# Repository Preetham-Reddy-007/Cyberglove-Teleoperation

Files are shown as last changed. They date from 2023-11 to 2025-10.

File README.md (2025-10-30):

# Cyberglove Teleoperation

A real-time teleoperation system that uses a sensor-equipped cyber glove to remotely control a Dobot robotic arm. The system captures hand movements and finger positions through flex sensors and an IMU, transmitting the data wirelessly via MQTT to control a robotic gripper with precision.

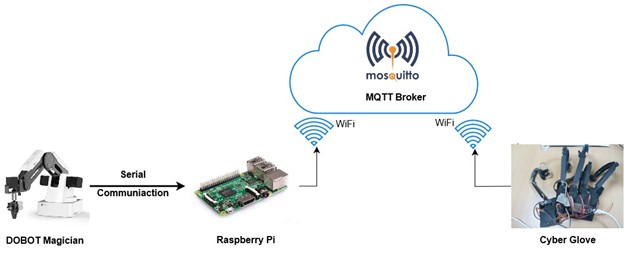
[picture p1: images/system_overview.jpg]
Cyberglove System Overview


## Table of Contents
- [Overview](#overview)
- [Features](#features)
- [System Architecture](#system-architecture)
- [Hardware Components](#hardware-components)
- [Software Components](#software-components)
- [Circuit Diagram](#circuit-diagram)
- [3D Printed Components](#3d-printed-components)
- [Installation](#installation)
- [Usage](#usage)
- [MQTT Communication](#mqtt-communication)
- [Directory Structure](#directory-structure)
- [Dependencies](#dependencies)
- [License](#license)

## Overview

The Cyberglove Teleoperation system enables intuitive remote control of robotic manipulators through natural hand movements. The system consists of:

1. **Cyber Glove**: A wearable device with flex sensors that measure finger joint angles (0-107 degrees) and an MPU6050 IMU for hand orientation tracking
2. **ESP32 Microcontroller**: Processes sensor data and transmits it via MQTT protocol
3. **MQTT Broker**: Handles wireless communication between the glove and robot controller
4. **Robot Controller**: Python-based controller that receives commands and operates the Dobot robotic arm
5. **Feedback System**: Provides force feedback via servos and tactile feedback via vibration motors

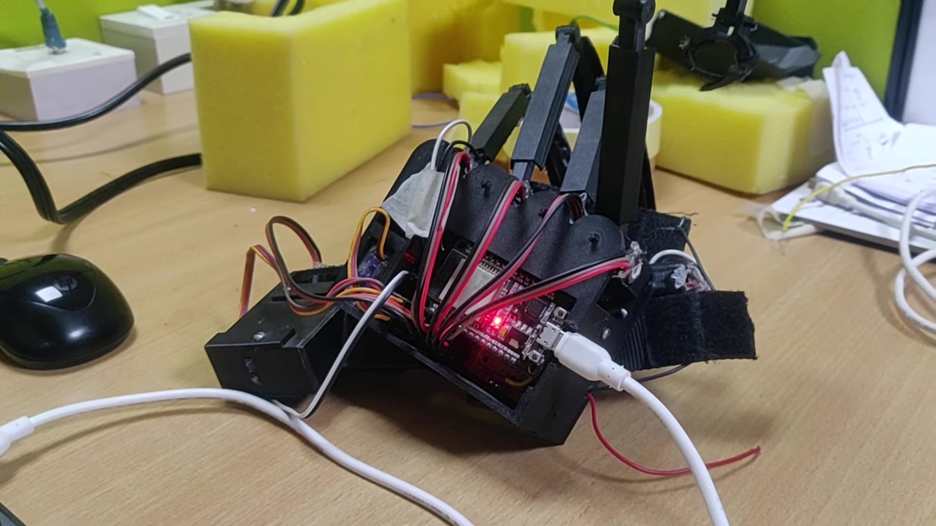
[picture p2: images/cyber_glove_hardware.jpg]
Cyber Glove Hardware


## Features

### Sensing Capabilities
- **5-Finger Joint Angle Tracking**: Independent measurement for thumb, index, middle, ring, and little fingers
- **Hand Orientation Tracking**: Real-time roll, pitch, and yaw angles using MPU6050 IMU
- **Second-Order Butterworth Filter**: Applied to sensor readings for noise reduction
- **20-Sample Moving Average**: Additional smoothing for potentiometer readings

### Control Features
- **Real-Time Teleoperation**: Low-latency control via MQTT protocol
- **Workspace Limitation**: Safety constraints (195-270mm radial workspace, 0-150mm vertical range)
- **Gripper Control**: Open/close gripper based on finger position
- **Web Interface**: Real-time visualization of joint angles and orientation via WebSocket

### Feedback Systems
- **Force Feedback**: Servo motors provide resistance when gripping objects
- **Tactile Feedback**: Vibration motors simulate touch sensations
- **Visual Feedback**: Web-based dashboard showing all sensor values

## System Architecture

The system uses a distributed architecture with the following components:

```
┌─────────────────┐         ┌──────────────┐         ┌─────────────────┐
│   Cyber Glove   │         │     MQTT     │         │  Dobot Robot    │
│   (ESP32)       │◄───────►│    Broker    │◄───────►│  Controller     │
│  - Flex Sensors │  WiFi   │              │  WiFi   │  (Python)       │
│  - IMU (MPU6050)│         │              │         │  - pydobot      │
│  - Servos       │         │              │         │  - paho-mqtt    │
│  - Vibrators    │         │              │         │                 │
└─────────────────┘         └──────────────┘         └─────────────────┘
        │                                                      │
        │                                                      │
        ▼                                                      ▼
┌─────────────────┐                              ┌─────────────────┐
│  Web Interface  │                              │  Robot Actions  │
│  (WebSocket)    │                              │  - Move (X,Y,Z) │
│  - Joint Angles │                              │  - Grip/Release │
│  - Orientation  │                              │  - Workspace    │
└─────────────────┘                              └─────────────────┘
```

## Hardware Components

### Cyber Glove Components

| Component | Model/Type | Quantity | Purpose |
|---|---|---|---|
| Microcontroller | ESP32 | 1 | Main processor for sensor reading and communication |
| IMU | MPU6050 | 1 | Measures hand orientation (roll, pitch, yaw) |
| Flex Sensors | Analog Potentiometers | 5 | Measure finger joint angles |
| Servo Motors | Standard Servo | 2 | Provide force feedback (thumb & index) |
| Vibration Motors | DC Vibration Motors | 2 | Provide tactile feedback |
| 3D Printed Parts | PLA/ABS | Multiple | Mechanical structure and sensor mounting |

### Pin Configuration (ESP32)

**Analog Input Pins (Flex Sensors):**
- GPIO 36: Thumb sensor
- GPIO 39: Index finger sensor
- GPIO 34: Middle finger sensor
- GPIO 35: Ring finger sensor
- GPIO 32: Little finger sensor

**Servo Control Pins:**
- GPIO 25: Thumb servo
- GPIO 33: Index finger servo

**Vibration Motor Pins:**
- GPIO 2: Thumb vibration motor
- GPIO 4: Index finger vibration motor

**IMU Interface:**
- GPIO 21: SDA (I2C Data)
- GPIO 22: SCL (I2C Clock)
- GPIO 5: Interrupt pin

**Status LED:**
- GPIO 17: System status LED

## Software Components

### 1. Cyber Glove Firmware
- **File**: `Cyber Glove/Project_iot_cyber_glove/cyber_glove_release_sw/cyber_glove_release_sw.ino`
- **Functions**:
  - Reads 5 flex sensors with second-order Butterworth filtering
  - Processes MPU6050 IMU data using DMP (Digital Motion Processor)
  - Hosts web server for visualization (port 80)
  - WebSocket server for real-time updates (port 81)
  - Controls force and tactile feedback systems

### 2. ESP32 MQTT Publisher
- **File**: `ESP32/Mosquitto_Write/Mosquitto_Write.ino`
- **Functions**:
  - Reads 4 potentiometer values (X, Y, Z, Gripper)
  - Applies 20-sample moving average filter
  - Maps sensor values to 0-127 range
  - Publishes data to MQTT topic `ESP32/Potentiometerdataread` every 5 seconds

### 3. Dobot Robot Controller
- **File**: `Dobot/PahoFinal.py`
- **Functions**:
  - Subscribes to MQTT topic for glove data
  - Maps sensor values to robot workspace coordinates
  - Enforces workspace constraints (195-270mm radial, 0-150mm height)
  - Controls Dobot arm position and gripper state
  - Uses pydobot library for robot communication

### 4. Additional Scripts
- `Dobot/FinalWspc.py`: Alternative workspace configuration
- `Dobot/PahoFinal2.py`: Alternative MQTT implementation
- `PahoConnect.py`: MQTT connection testing utility

### Sensor Calibration Values

The system uses calibration offsets for accurate angle measurement:

```cpp
// Joint Angle Offsets (raw ADC values)
const float ind_off = 878.0;   // Index finger
const float mid_off = 785.0;   // Middle finger
const float rng_off = 1179.0;  // Ring finger
const float lil_off = 950.0;   // Little finger
const float thb_off = 895.0;   // Thumb

// Joint Angle Ranges (raw ADC values)
const float ind_range = 1794.0;
const float mid_range = 1708.0;
const float rng_range = 1684.0;
const float lil_range = 1845.0;
const float thb_range = 1958.0;

// Angular range in degrees
const float delta_ang = 107.0;
```

## 3D Printed Components

The cyber glove uses custom 3D printed parts for mechanical structure and sensor mounting. STL files are provided for both right-hand (default) and left-hand configurations.

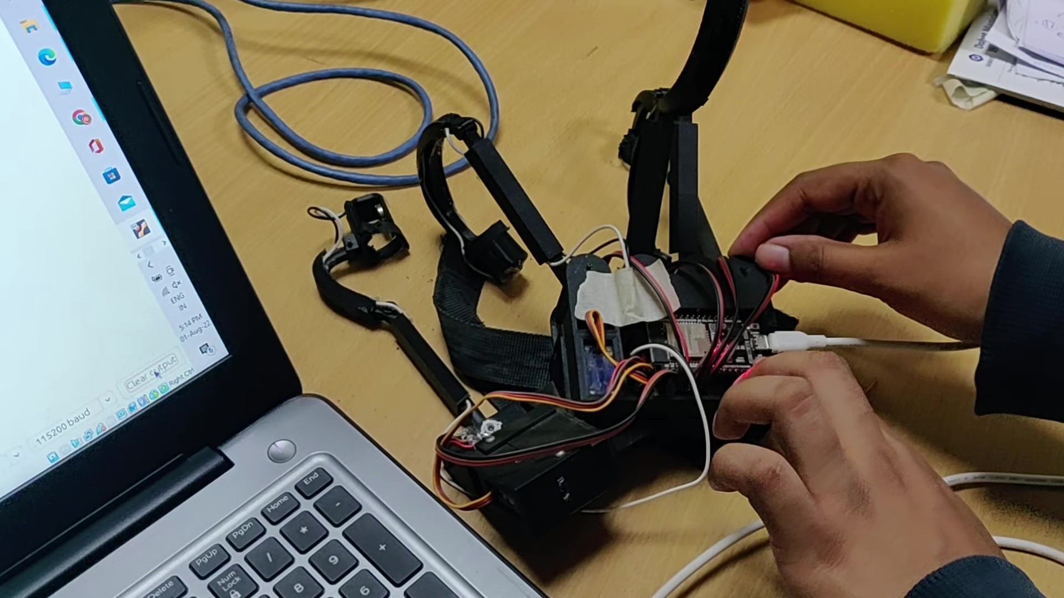
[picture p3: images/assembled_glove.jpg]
Assembled Glove


### Parts List

**Finger Mechanisms:**
- `bottom holder.STL` / `top holder.STL`: Main mounting brackets
- `mid_ring_ind_finger link.STL`: Link mechanism for index, middle, ring fingers
- `mid_ring_ind_finger cover.STL`: Protective cover
- `little finger link.STL` / `little finger cover.STL`: Little finger mechanism
- `thumb attachment.STL` / `thumblink.STL`: Thumb mechanism
- `thumb upper holder.STL` / `thumb lower holder.STL`: Thumb mounting
- `thumb cover.STL` / `thbl2cvr.STL`: Thumb protective covers

**Sensor Mounts:**
- `finger tip version1.STL`: Fingertip sensor housing
- `tip with mot.STL`: Motorized fingertip
- `rachet_joint.STL`: Ratcheting joint mechanism
- `rachet link.STL` / `rachet link cover.STL`: Ratchet link assembly

**Electronics Housing:**
- `pcbholder.STL`: PCB mounting bracket
- `cover plate.STL`: Electronics cover
- `slider2.STL` / `slide1_1_1.STL` / `slide_1_1_2.STL`: Adjustment sliders

**Left-Hand Version:**
All parts are available in mirrored versions in the `STL_Files_Left_Hand/` directory.

### Printing Recommendations

- **Material**: PLA or ABS
- **Layer Height**: 0.2mm
- **Infill**: 20-30%
- **Supports**: Required for some parts
- **Print Orientation**: Follow guidelines in `STL_Files_Left_Hand/Readme cyber glove prints.pdf`

## Installation

### Hardware Setup

1. **3D Print Components**
   - Print all required STL files from the `Cyber Glove/cyber glove/` directory
   - Use appropriate material (PLA/ABS) with 20-30% infill
   - Refer to `STL_Files_Left_Hand/Readme cyber glove prints.pdf` for printing guidelines

2. **Assemble Cyber Glove**
   - Mount flex sensors in finger mechanisms
   - Install MPU6050 IMU on the back of hand
   - Connect servos for force feedback
   - Install vibration motors
   - Wire all components to ESP32 according to pin configuration

3. **Connect Dobot Robot**
   - Connect Dobot arm to computer via USB (typically `/dev/ttyUSB2` on Linux)
   - Ensure robot is powered and initialized

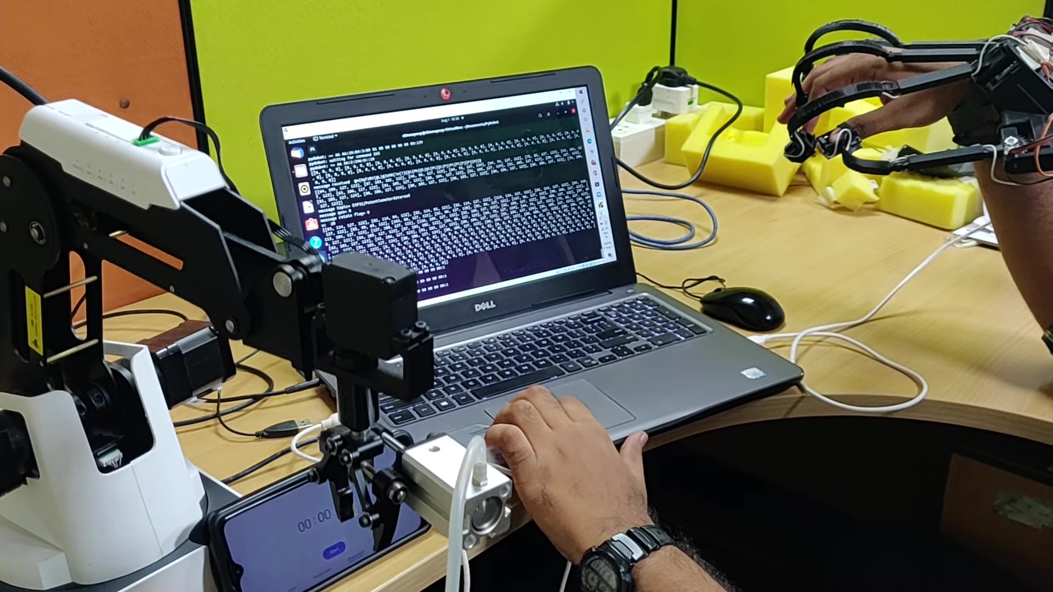
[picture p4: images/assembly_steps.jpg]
Assembly Steps


### Software Setup

#### 1. ESP32 Firmware

Install required libraries in Arduino IDE:
```bash
# Arduino Libraries needed:
- WiFi (built-in)
- PubSubClient
- ArduinoJson
- WebSocketsServer
- ESP32Servo
- MPU6050 (I2Cdev library)
```

Configure WiFi and MQTT:
```cpp
// In cyber_glove_release_sw.ino or Mosquitto_Write.ino
const char* ssid = "YOUR_WIFI_SSID";
const char* password = "YOUR_WIFI_PASSWORD";
const char* mqtt_server = "YOUR_MQTT_BROKER_IP";
```

Upload firmware to ESP32.

#### 2. MQTT Broker

Install Mosquitto MQTT broker:
```bash
# Ubuntu/Debian
sudo apt-get update
sudo apt-get install mosquitto mosquitto-clients

# macOS
brew install mosquitto

# Start the broker
mosquitto -v
```

Or use a cloud MQTT broker:
- `broker.mqtt-dashboard.com`
- `broker.emqx.io`

#### 3. Python Environment

Install Python dependencies:
```bash
pip install pydobot paho-mqtt
```

For Dobot robot, you may need additional setup:
```bash
# Linux: Add user to dialout group for USB access
sudo usermod -a -G dialout $USER
```

Configure Python script:
```python
# In Dobot/PahoFinal.py
broker_address = "YOUR_MQTT_BROKER_IP"  # e.g., "192.168.1.100"
port = "/dev/ttyUSB2"  # Adjust for your system (COM port on Windows)
```

## Usage

### 1. Start MQTT Broker

```bash
mosquitto -v
```

### 2. Power On Cyber Glove

- Power the ESP32 (via USB or battery)
- Wait for WiFi connection (check Serial Monitor)
- Note the IP address displayed

### 3. Access Web Interface

Open a browser and navigate to the ESP32's IP address:
```
http://[ESP32_IP_ADDRESS]
```

The interface displays:
- Real-time finger joint angles
- Hand orientation (roll, pitch, yaw)
- Force feedback status
- Tactile feedback status
- Control buttons for feedback activation

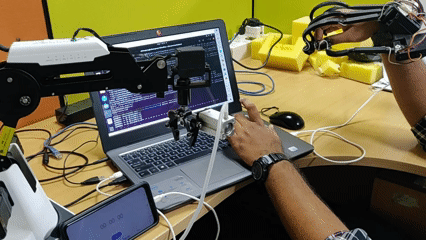
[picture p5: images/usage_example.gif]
Usage Example


### 4. Start Robot Controller

```bash
cd Dobot
python PahoFinal.py
```

The script will:
- Connect to MQTT broker
- Move Dobot to home position (234, 0, 75, 0)
- Subscribe to glove data
- Begin real-time teleoperation

### 5. Operate the System

- Move your hand to control robot position
- Finger movements map to X, Y, Z coordinates
- Close fingers to activate gripper
- System enforces workspace constraints for safety

### Control Mapping

| Glove Input | Robot Output | Range |
|---|---|---|
| X-axis finger angle | Robot X position | 195-270mm |
| Y-axis finger angle | Robot Y position | 195-270mm |
| Z-axis finger angle | Robot Z position | 0-150mm |
| Gripper sensor | Gripper state | Open/Close |
| Hand roll/pitch/yaw | (Future: Wrist orientation) | ±180° |

## MQTT Communication

### Topic Structure

- **Publisher**: ESP32 Cyber Glove
- **Topic**: `ESP32/Potentiometerdataread`
- **Subscriber**: Python Robot Controller
- **Message Format**: 4-byte character array `[X, Y, Z, Gripper]`
- **Update Rate**: Every 5 seconds
- **QoS Level**: 0 (At most once)

### Data Format

```
Message: [dx, dy, dz, dg]
  dx: X-axis value (0-127)
  dy: Y-axis value (0-127)
  dz: Z-axis value (0-127)
  dg: Gripper value (0-127)
    - dg ≤ 63: Grip closed
    - dg > 63: Grip open
```

### Coordinate Transformation

```python
# Sensor to robot workspace mapping
xa = (dx * 270) / 127  # Map to 0-270mm
ya = (dy * 270) / 127
za = (dz * 150) / 127  # Map to 0-150mm

# Workspace validation
radius = sqrt(xa² + ya²)
if 195 <= radius <= 270 and 0 <= za <= 150:
    # Valid workspace - execute movement
    device.move_to(xa, ya, za, r, wait=True)
```

## Directory Structure

```
Cyberglove-Teleoperation/
├── Cyber Glove/
│   ├── Project_iot_cyber_glove/
│   │   ├── cyber_glove_release_sw/          # Main cyber glove firmware
│   │   ├── robot_gripper_release_sw/        # Gripper control firmware
│   │   ├── Readme.pdf                       # Hardware documentation
│   │   ├── presentation_HW_SW_architecture.pdf
│   │   └── system_schematic.pdf             # System wiring diagram
│   └── cyber glove/                         # 3D model STL files (right hand)
│       ├── bottom holder.STL
│       ├── top holder.STL
│       └── [... other STL files]
├── STL_Files_Left_Hand/                     # 3D model STL files (left hand)
│   ├── Readme cyber glove prints.pdf        # Printing instructions
│   └── [... mirrored STL files]
├── Dobot/
│   ├── PahoFinal.py                         # Main robot controller
│   ├── PahoFinal2.py                        # Alternative implementation
│   ├── FinalWspc.py                         # Workspace utilities
│   └── FinalWspc2.py
├── ESP32/
│   ├── Mosquitto_Write/                     # MQTT publisher (simple version)
│   ├── Mosquitto_Write2/
│   ├── Mosquitto_Read/                      # MQTT subscriber test
│   ├── CloudWriteAvg/                       # Cloud MQTT implementation
│   ├── CloudReadAvg/
│   ├── Serial/                              # Serial communication test
│   └── Test_Array/                          # Array data handling test
├── PahoConnect.py                           # MQTT connection tester
├── Documentation.docx                       # Project documentation
├── LICENSE                                  # MIT License
└── README.md                                # This file
```

## Dependencies

### Hardware
- ESP32 Development Board (WROOM-32 or similar)
- MPU6050 6-axis IMU
- 5x Analog flex/potentiometer sensors
- 2x Servo motors (for force feedback)
- 2x Vibration motors (DC motors)
- Dobot Magician robotic arm
- WiFi network
- 3D printer for mechanical parts

### Software

**Arduino Libraries:**
```
WiFi
PubSubClient (MQTT)
ArduinoJson
WebSocketsServer
ESP32Servo
Wire (I2C)
I2Cdev
MPU6050 (DMP)
```

**Python Packages:**
```
pydobot>=1.3.0
paho-mqtt>=1.5.0
```

**System Requirements:**
```
Arduino IDE 1.8.x or higher (or PlatformIO)
Python 3.6 or higher
Mosquitto MQTT Broker 1.6 or higher
```

## Calibration

### Flex Sensor Calibration

1. Open `cyber_glove_release_sw.ino`
2. Read raw ADC values with fingers straight (offsets)
3. Read raw ADC values with fingers fully bent (ranges)
4. Update calibration constants:
   ```cpp
   const float ind_off = YOUR_VALUE;
   const float ind_range = YOUR_VALUE;
   // Repeat for all fingers
   ```

### IMU Calibration

Run the MPU6050 calibration sketch and update:
```cpp
mpu.setXGyroOffset(YOUR_VALUE);
mpu.setYGyroOffset(YOUR_VALUE);
mpu.setZGyroOffset(YOUR_VALUE);
mpu.setZAccelOffset(YOUR_VALUE);
```

### Workspace Calibration

Adjust robot workspace limits in `PahoFinal.py`:
```python
# Radial workspace (mm)
if 195 <= sqrt <= 270:
    # Adjust these values based on your robot

# Vertical workspace (mm)
if 0 <= za <= 150:
    # Adjust these values based on your robot
```

## Troubleshooting

**ESP32 not connecting to WiFi:**
- Verify SSID and password
- Check 2.4GHz WiFi network (ESP32 doesn't support 5GHz)
- Monitor serial output for connection status

**MQTT messages not received:**
- Verify broker is running: `mosquitto -v`
- Check broker IP address in both ESP32 and Python code
- Test with mosquitto_sub: `mosquitto_sub -t "ESP32/Potentiometerdataread"`

**Dobot not responding:**
- Check USB connection and permissions
- Verify port in Python script (e.g., `/dev/ttyUSB2`, `COM3`)
- Ensure pydobot is installed correctly

**Inaccurate sensor readings:**
- Recalibrate flex sensors
- Check for loose connections
- Verify power supply stability
- Adjust filter parameters if needed

## Future Enhancements

- [ ] Add hand orientation control for robot wrist
- [ ] Implement bilateral force feedback
- [ ] Add multiple robot support
- [ ] Develop smartphone app for monitoring
- [ ] Add gesture recognition for complex commands
- [ ] Implement machine learning for motion prediction
- [ ] Add VR/AR visualization
- [ ] Support for other robot platforms

## Contributing

Contributions are welcome! Please feel free to submit pull requests or open issues for bugs and feature requests.

## License

This project is licensed under the MIT License - see the [LICENSE](LICENSE) file for details.

## Acknowledgments

- MPU6050 DMP library by Jeff Rowberg
- pydobot library for Dobot control
- Eclipse Paho for MQTT implementation

## Contact

For questions or support, please open an issue in the GitHub repository.

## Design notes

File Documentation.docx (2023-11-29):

Teleoperation of DOBOT Magician using Cyber Glove

2022

Index

1. Step 1 : Set up the ORACLE Virtual Box
2. Step 2 : Arduino IDE Installation and ESP 32 Package Installation
3. Step 3 : DOBOT Magician Python API Interface and Setup
4. Step 4 : MQTT Protocol Implementation

ORACLE Virtual Box

Note: If you work on an Ubuntu System, you can skip this step.

Installing Oracle Virtual Box (VB) : Oracle Website -> Windows host -> download latest version

When you want to update Virtual Box to latest version, uninstall and download the latest file from their website. The virtual machines will be auto present when you open the updated virtual box. Don’t upgrade directly, as you might get kernel issues.

Ubuntu ISO : Go to Ubuntu website and download the iso file.

I Setup new Virtual Machine in Oracle VB

All downloads done within virtual box in ubuntu 20.04 .

Open the VB

1. New virtual Machine: Type: Linux

Version: Ubuntu 64bit

Hard Disk: 4000MB

Memory: 25GB

2. System Settings : Install Ubuntu Image (Downloaded earlier) from downloads
3. USB Settings :
- In settings click the USB tab.
- On the right side, click the usb icon with a green plus sign.
- Add anything with Silicon Labs USB to Uart Bridge controllers, or anything with Cygnal
- Integrated products CP210x Uart bridge. If you don't see these Options you many need
- to download drivers for your platform here (https://www.silabs.com/developers/usb-to-uart-bridge-vcp-drivers).

( https://www.silabs.com/developers/usb-to-uart-bridge-vcp-drivers )

- Select English, install Ubuntu
- Select keyboard, English(US)
- Select Normal Installation & Download updates while installing Ubuntu
- Since you are using a virtual machine you can select erase disk and install.
- Username : “Set your username”
- Pswrd : “Set your password”

//Takes time to install.

- Connect your online accounts : Skip
- Right ctrl (Host button) + F : Full screen
- But you might get black screen around the box
- So go to devices -> Insert guest additions CD image -> put your password : it will download -> then shutdown ubuntu -> and start again -> press right ctrl + F

For all Ubuntu distributions run these commands after a fresh install.

- sudo apt install gcc g++ cmake putty unzip curl
- sudo apt update
- sudo apt upgrade
- If you are on a virtual machine (Virtual Box), at the top of the window click Devices
  - Shared Clipboard set to bidirectional
  - Drag and Drop set to bidirectional
  - Finally click Insert guest additions CD Image
  - Once done installing in terminal input reboot

These steps are not mandatory. They just make working inside the virtual box easier.

Arduino IDE Installation and ESP 32 Package Installation

Use snap to download Arduino as given in the following website: https://linoxide.com/how-to-install-arduino-ide-on-ubuntu-20-04/

You need to type ./install.sh instead. The ./ indicates that you want to run a file in your current working directiry. Without the leading ./ linux will search in your $PATH for an executable program with that name.

Follow the following steps to add esp32 dev board package to the ide.

1. Go to File -> Preferences -> In additional boards manager URL : https://dl.espressif.com/dl/package_esp32_index.json
2. Then click Ok
3. Tools -> Boards -> No ES32 -> so go to Boards Manager -> type esp32 -> Install the package that shows up
4. Go to Tools -> Boards -> ESP 32 dev board

(https://randomnerdtutorials.com/installing-the-esp32-board-in-arduino-ide-mac-and-linux-instructions/)

(http://arduino-er.blogspot.com/2020/06/install-esp32esp8266-to-arduino-ide-on.html)

Go through the above two URLs for further reference.

# When IDE is first installed, no libraries are present. So install them from library manager and git hub profiles online as zip files and then add them.

DOBOT Magician Python API Interface and Setup

The DOBOT Magician has a DOBOT API interfaced with a python API. This API can be accessed using the PyDobot library available at : https://github.com/luismesas/pydobot

The setup for the same is as follows,

Terminal:

- Install: Python3 (You will need Python 2.7 or Python 3.x. Download “ https://www.python.org/ “ and install.)
- Pip is a python library manager. Pip drivers and Pip module allow Python functions to run in terminal. ( https://linuxize.com/post/how-to-install-pip-on-ubuntu-18.04/ )
- Install Pydobot (Install Pydobot using pip (command : pip install pydobot))

You can also download its zip file from: https://github.com/luismesas/pydobot

- You will also need pyserial module. pip install pyserial (If pyserial is not installed exceptions will be thrown when executing examples)
- Download the CP210x USB to UART Bridge VCP Drivers from https://www.silabs.com/developers/usb-to-uart-bridge-vcp-drivers
- Use the commands ‘groups’ to check what groups are you a part of. Use ‘sudo usermod -a ubuntu -G dialout’ or ‘newgrp dialout’ to add yourself (username here: ubuntu) to dialout group and similarly to ttl group as well.
- The dialout group helps you control the usb ports without which you will be thrown the error ‘port access denied’.
- And every time you add yourself to a new group make sure you reboot.

To Run the python scripts for Dobot control:

- Open Ubuntu VB
- Open Terminal
- Check if pydobot library is installed : pip3 show pydobot
- Connect DOBOT Magician to laptop using USB port and power it on. The Dobot takes a few seconds to initialize.
- Check Devices -> USB -> Silicon Labs is detected
- Use dmesg command and lusb commands to identify what port is selected and make the corresponding changes in the script (ttyUSB0/1/2 *)

( USB tab under devices may not show the silicon labs port if it isn’t added in the virtual box , so make sure to add it in USB settings in the VB first using the green plus usb icon.)

Note: If the module you are trying to import i.e. the library , and any of your python files are named the same , then you will get a circular error. So make sure they are named differently.

Generally, the Python Circular Import problem occurs when you accidentally name your working file the same as the module name and those modules depend on each other. This way the python opens the same file again and again which causes a circular loop and eventually throws an error.

- In Terminal : execute the file

cd Documents/PyDobot (location where the file is stored)

python3 Py.py (here Py.py is the file you are trying to run)

Note: To compile python files : python -m py_serial Py.py or python3 -m py_serial Py.py

Note: Information on how to operate and troubleshoot technical issues with the Dobot Magician are provided in the manual – Dobot Magician User Guide, download-able from their website.

The Dobot Studio is their official application which can be downloaded from their website and installed on your system.

PyDobot is an unofficial python library that utilizes the python API interfaced with the Dobot API for control of DOBOT Magician.

Note: Fix port access on Linux : https://support.arduino.cc/hc/en-us/articles/360016495679-avrdude-ser-open-can-t-open-device-Permission-denied-Linux-

It will give you the importance of ‘dialout’ group.

Note : When you add yourself to a new group, for the effect to take place the system needs to be rebooted.

The USB connection is not handled by the ESP32, as an ESP32 only has serial lines (rx and tx), no USB. A dev board typically includes some sort of USB to serial converter chip (sometimes refered to as FTDI). This chip communicates with your computer, resulting in the creation of a virtual COM port. If you have a driver for that chip installed, otherwise it won't work. Without a driver the chip probably turns up as unsupported or unrecognized device in your hardware list. Although the ESP32 module may be the same, you might have a dev board with a different USB to serial converter than other devices you might have tested on your computer. So if one dev board works and another one doesn't, that does not necessarily mean the board is defective. You might just need to install a driver for the USB to serial chip on your dev board.

MQTT Protocol Implementation

Refer: Mosquitto MQTT Broker: Tutorial for Installation on Ubuntu 20.04 | ArubaCloud.com (https://www.arubacloud.com/tutorial/how-to-install-and-secure-mosquitto-on-ubuntu-20-04.aspx)

http://mosquitto.org/

Programs included : There are two folders : Dobot and ESP32

Dobot contains the programs used for operating the Dobot Magician.

ESP32 contains the programs running on both the esp32 s.

THINGSPEAK | CloudWriteAvg | Glove | Writes the potentiometer data to ThingSpeak Cloud Server using write API key over HTTP protocol.
| CloudReadAvg | ESP32 | Reads the potentiometer data from ThingSpeak Cloud Server using read API key over HTTP protocol.
| FinalWspc.py | Terminal | Operates the DOBOTMagician in the positive workspace.
MOSQUITTO (No Fidelity) | Mosquitto_Write | Glove | Publishes potentiometer data to the MOSQUITTO Broker running on the computer using MQTT v3.1.1 .
| Mosquitto_Read | ESP32 | Subscribes the potentiometer date from the MOSQUITTO Broker running on the computer using MQTT v3.1.1 .
| FinalWspc.py | Terminal | Operating the DOBOTMagician in the positive workspace.
MOSQUITTO (With Fidelity) | MosquittoWrite2 | Glove | Publishes potentiometer data to the MOSQUITTO Broker running on the computer using MQTT v3.1.1 .
| PahoFinal.py | Terminal | Subscribes to the Mosquitto broker using Paho client.
| Test_Array | Glove | Publishes potentiometer data. Takes 20 values, each at an interval of 250ms. Publishes it at an interval of 7s.
| PahoFinal2.py | Terminal | Subscribes and executes the 20 values.
| PahoFinal2copy.py | Terminal | Subscribes and executes the values but has a buffer to continuously take values from the glove.
Serial | Serial | Glove | Sends Potentiometer Data over serial communication
| FinalWspc.py | Terminal | Operates the DOBOTMagician in the positive workspace.

Extra Programs:

PyDobot2.py : Vanilla program used to operate pydobot. Simple demonstration of the PyDobot library.

Position.py: Prints the cartesian co-ordinates of the end-effector and angular joint positions

Note : When flashing the esp32, press the Boot button continuously until the flashing is executed. Then press the

The EN button is connected to the EN pin on the ESP32, so pressing it will reset the ESP32.

The BOOT button is connected to GPIO0 (which is also a bootstrapping pin to set the boot mode (https://github.com/espressif/esptool/wiki/ESP32-Boot-Mode-Selection)), so pressing it will pull GPIO0 low

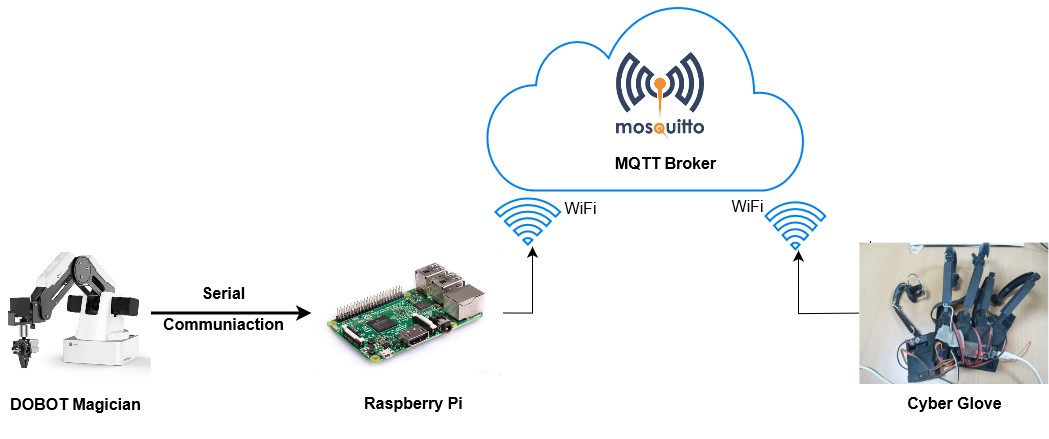
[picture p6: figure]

Protocol : MQTT

Broker : Mosquitto

Publishing Client : Raspberry Pi

Subscribing Client: Cyber Glove

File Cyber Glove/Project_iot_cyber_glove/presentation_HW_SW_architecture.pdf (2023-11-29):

# Cyber Glove

## 1. Objectives revisited 2. System configuration 3. Human Hand anatomy 4. Mechanical design 5. Hardware architecture 6. Software architecture

## System architecture and implementation plan - Preetham Reddy G

# Objectives Revisited

Accurate enough estimation
of kinematics.

Integration of haptic
feedback in the glove

Communication between
Glove and robotic hand

Ergonomic design of glove

Proposed Solution :
- Design of exoskeleton
without affecting any DOF
of hand

Proposed Solution :
- Use of Exoskeleton with
Ratchet mechanism to
provide digital force
feedback.
- Use of vibration motors for tactile feedback (touch)

Proposed Solution :
- WIFI connectivity for Line of sight connectivity
- Use of internet for Long distance communication
through wifi

Proposed Solution :
- Use of Exoskeleton with
rotational encoders for
finger kinematics
- And IMU for Yaw ,Pitch and Roll motion capturing

# Human Hand anatomy

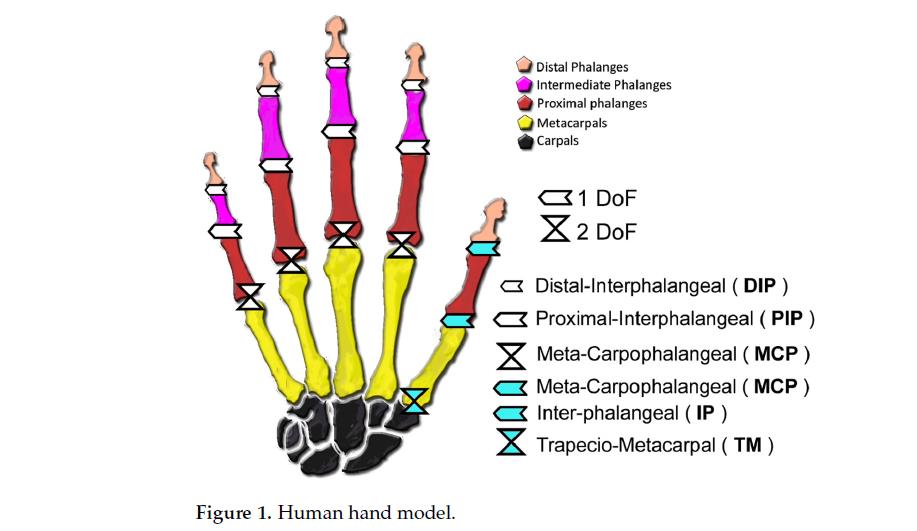
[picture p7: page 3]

# System Configuration

## - Easy to apply rigid body dynamics and kinematics to estimate the finger

kinematics.

## - Rotary encoders can be used which are very cheap (potentiometer)

- Excellent for “Force feedback”.

## exoskeleton helps in restricting the motion of fingers in controlled manner

## Exoskeleton configuration : Mechanical system designed around dynamic

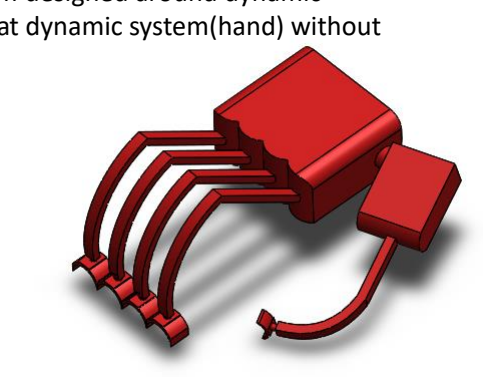
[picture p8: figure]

## system(hand) which mimics the motion of that dynamic system(hand) without

restricting the DOFs.

# Mechanical Design

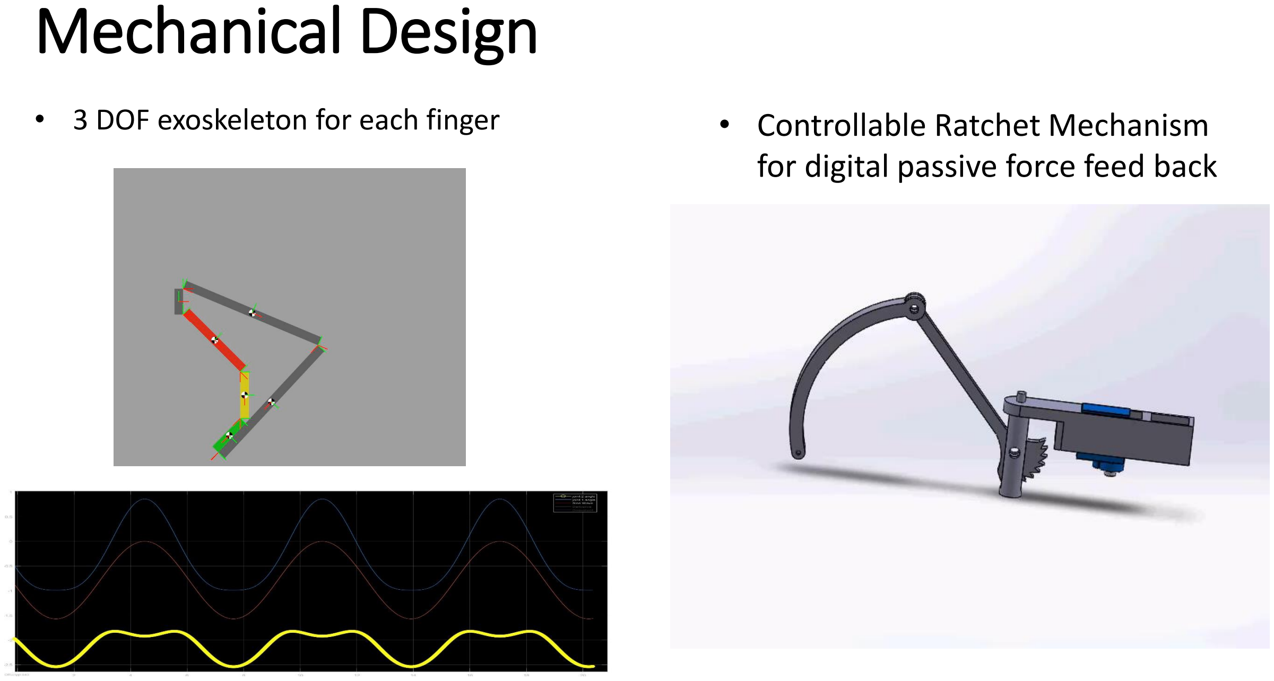
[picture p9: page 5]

- 3 DOF exoskeleton for each finger | • Controllable Ratchet Mechanism for digital passive force feed back

# Hardware architecture

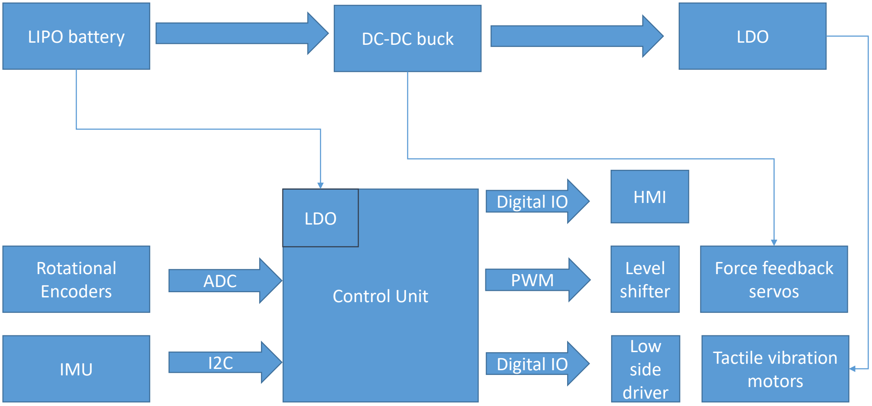
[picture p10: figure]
Rotational; Encoders; Control Unit; IMU; Force feedback servos; Tactile vibration motors; Low side driver; Level shifter ADC; PWM; Digital IO; LIPO battery; DC-DC buck; LDO; HMI

# Software Architecture

SOC abstraction layer

System On Chip

ADC drivers | PWM drivers | Digital IO | I2c comm.
drivers | Wi-Fi drivers

System related drivers

Hardware abstraction layer
Servo drive | Tactile Motor
drive | Encoder sensor | IMU | Power supply monitoring

Application layer

Kinematics
algorithm

IMU filter
algorithm

Haptic feedback
algorithm | HMI | Communication

# Small demo of active feedback

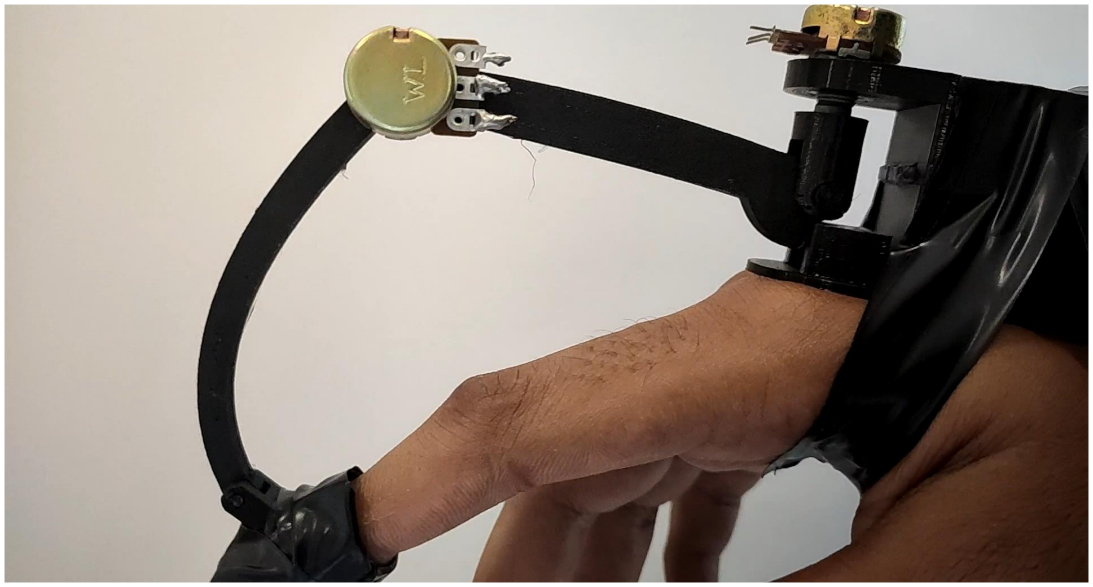
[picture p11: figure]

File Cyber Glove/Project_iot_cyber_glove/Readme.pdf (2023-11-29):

## The attached files are:

1. presentation_HW_SW_architecture.pptx
2. system_schematic.pdf
3. cyber_glove_release_sw.ino
4. robot_gripper_release_sw.ino
5. glove_server.txt

presentation_HW_SW_architecture.pptx :
This ppt has all the details regarding high level system design

### system_schematic.pdf :

This document has schematic level design which also includes boundary condition analysis, power calculation.

### cyber_glove_release_sw.ino :

This is final release of software version for exoskeleton based cyber glove which include sw components for

1. HW description
2. Calibration parameters
3. IMU
4. Rotary sensor interfacing with filtering.
5. Force feedback
6. Touch feedback
7. Websocket server
8. Webpage for testing

### robot_gripper_release_sw.ino :

This is final release of software version for Robot gripper and includes SW components for

1. HW description
2. Calibration parameters
3. Servo control
4. Pressure sensor interface and filtering
5. Websocket client

### glove_server.txt:

This has html description of webpage and java script for the same.

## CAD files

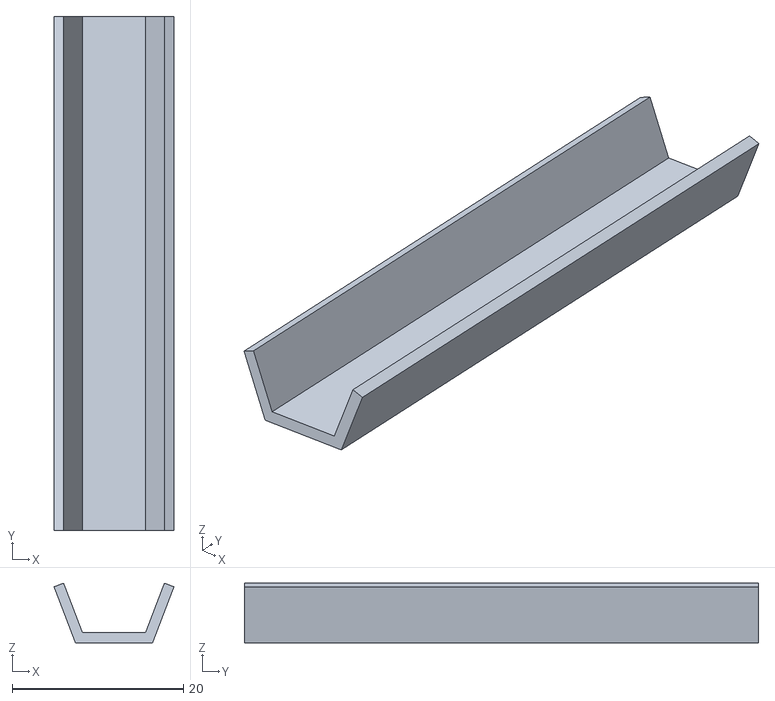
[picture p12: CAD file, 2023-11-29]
Cyber Glove/cyber glove/rachet link cover.STL
14.0 x 60.0 x 6.97

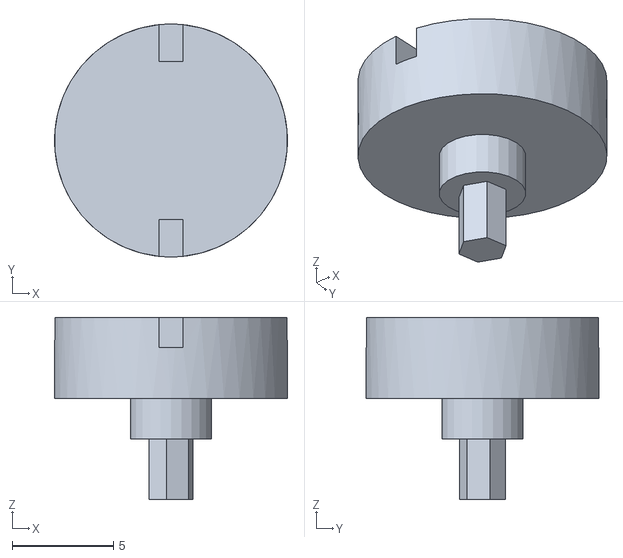
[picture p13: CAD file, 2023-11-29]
STL_Files_Left_Hand/Ratchet Joint 3.stl
11.5 x 11.5 x 9.00

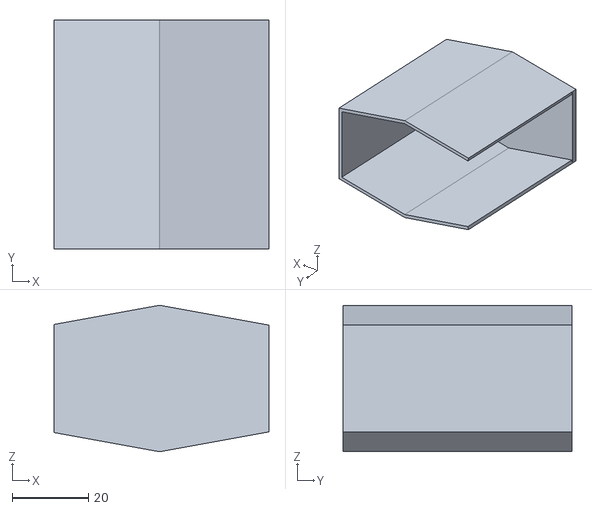
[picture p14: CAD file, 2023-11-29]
Cyber Glove/cyber glove/thumb cover.STL
56.4 x 60.0 x 38.4

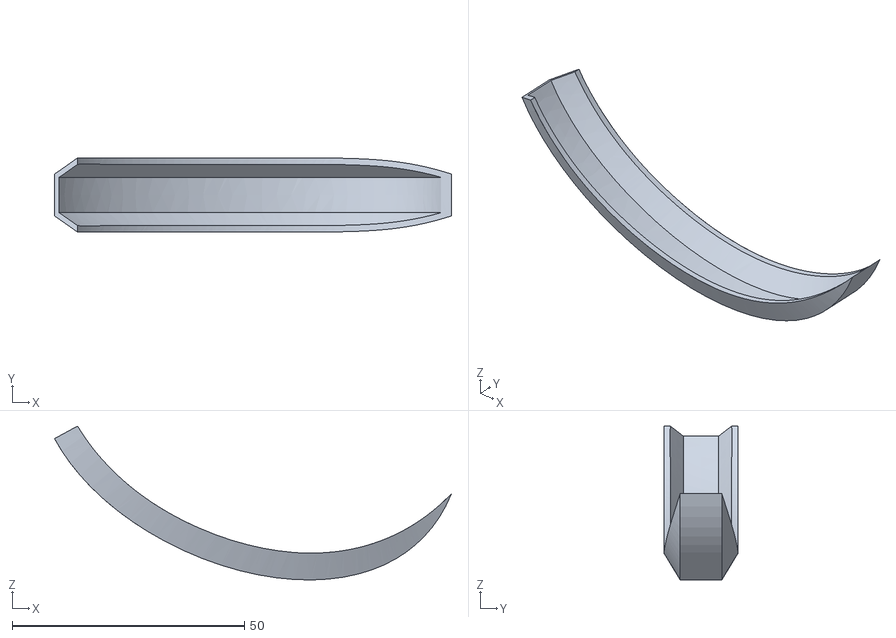
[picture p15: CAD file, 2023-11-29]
Cyber Glove/cyber glove/mid_ring_ind_finger cover.STL
85.5 x 16.0 x 33.1

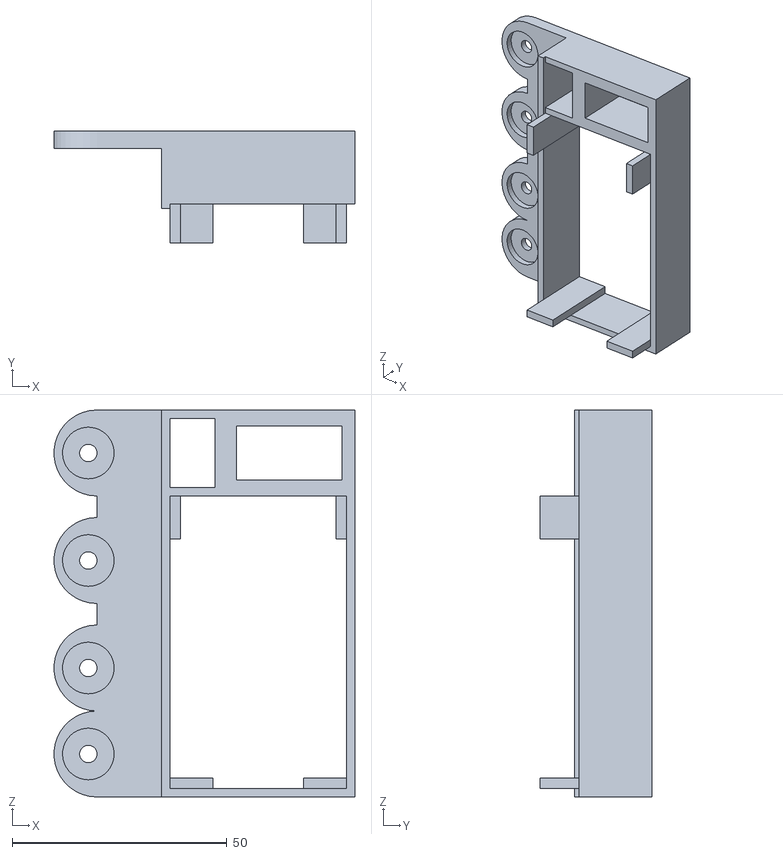
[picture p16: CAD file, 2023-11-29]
Cyber Glove/cyber glove/top holder.STL
70.0 x 26.0 x 90.0

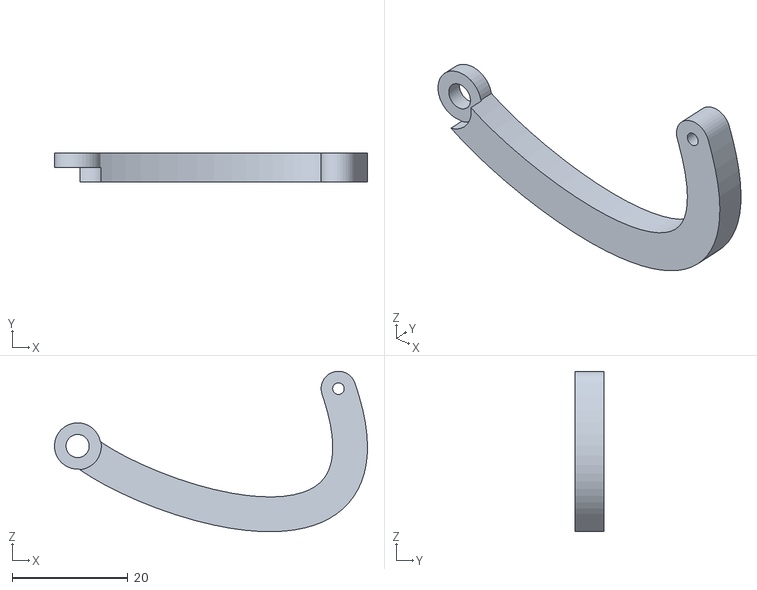
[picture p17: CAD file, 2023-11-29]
STL_Files_Left_Hand/thumblink.STL
54.0 x 5.00 x 27.7

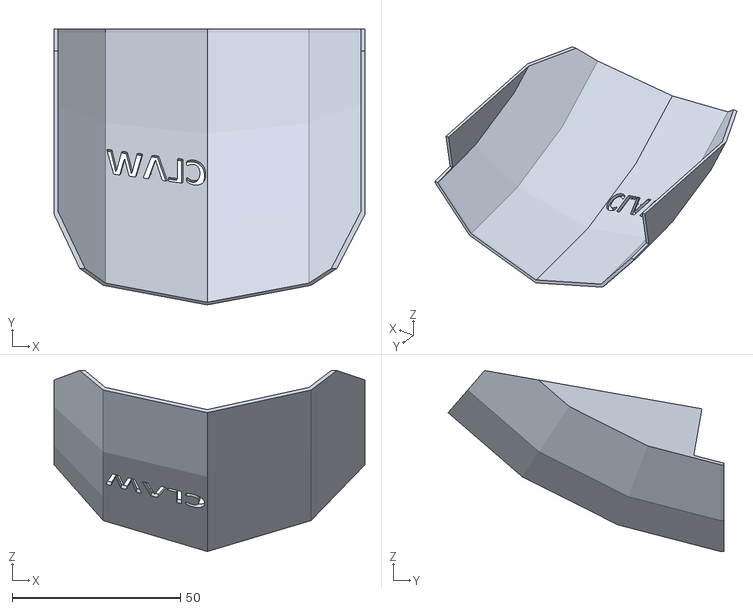
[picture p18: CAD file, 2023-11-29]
Cyber Glove/cyber glove/cover plate.STL
92.4 x 82.0 x 53.8

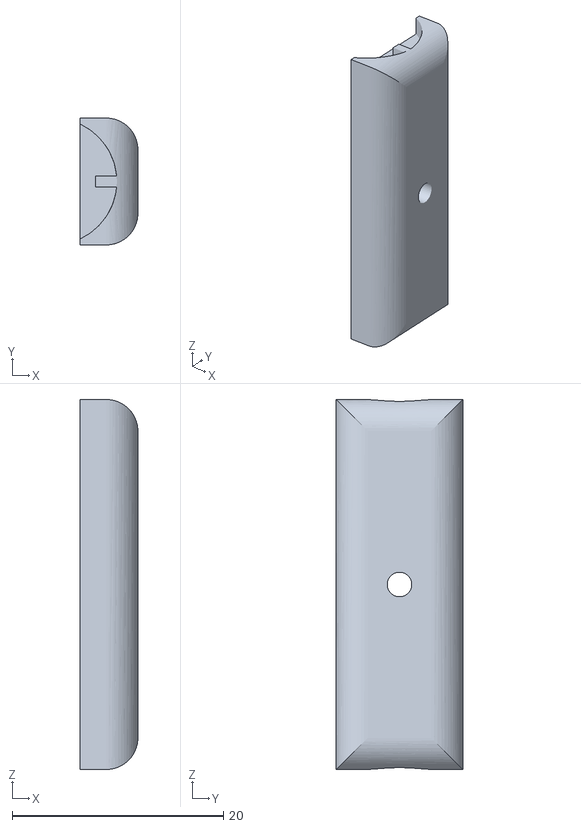
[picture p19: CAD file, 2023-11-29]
STL_Files_Left_Hand/Ratchet Joint 1.stl
5.47 x 12.0 x 35.0

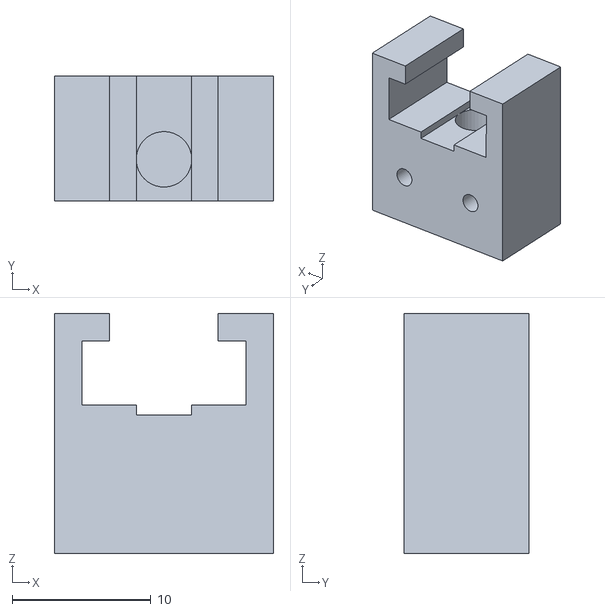
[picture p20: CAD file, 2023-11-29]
Cyber Glove/cyber glove/slide_1_1_2.STL
15.8 x 9.00 x 17.3

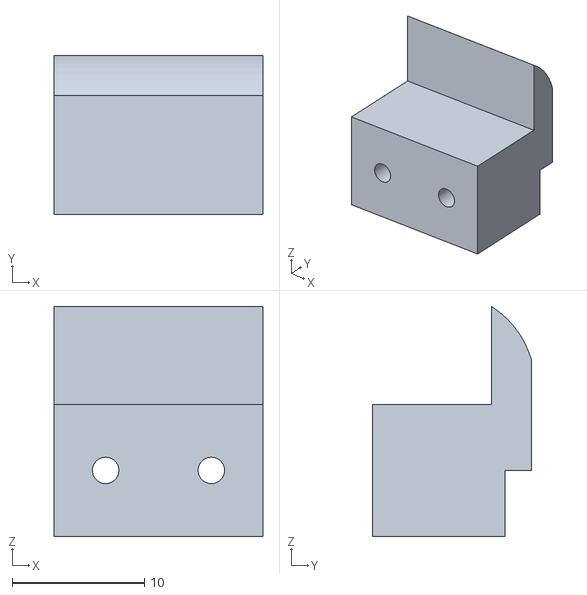
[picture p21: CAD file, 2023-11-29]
Cyber Glove/cyber glove/slider2.STL
15.8 x 12.0 x 17.4

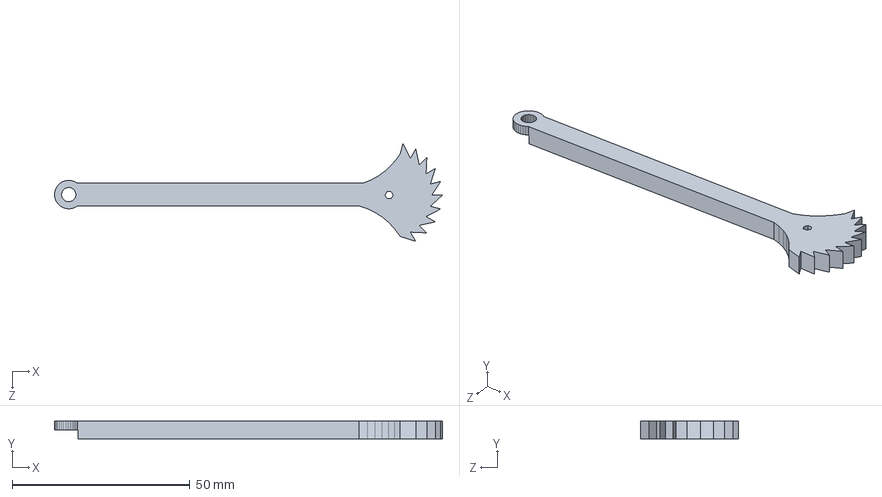
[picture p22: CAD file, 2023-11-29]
STL_Files_Left_Hand/Ratchet Link.SLDPRT
109.0 x 5.00 x 27.5 mm

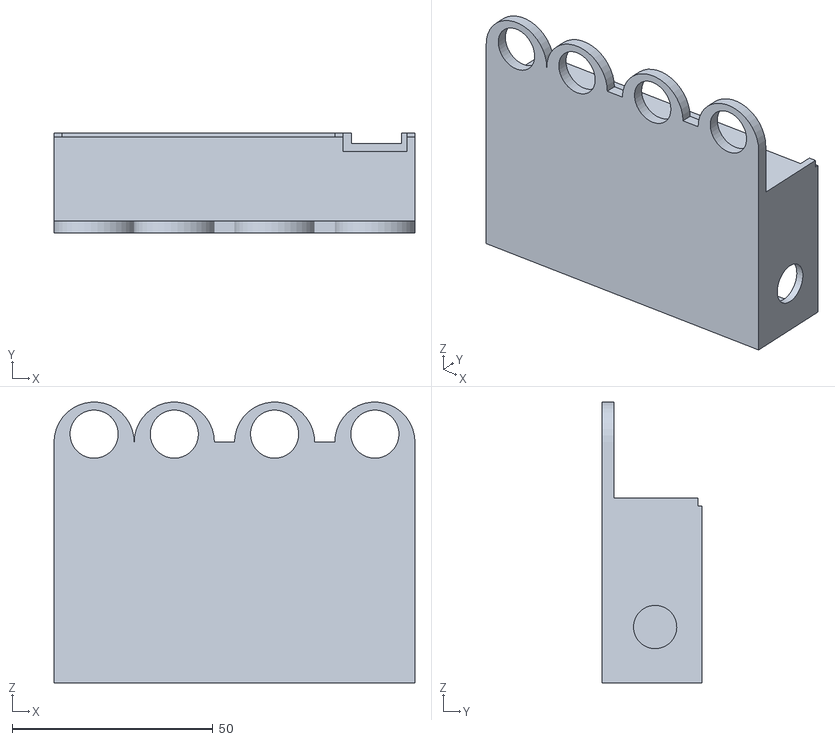
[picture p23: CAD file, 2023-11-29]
Cyber Glove/cyber glove/bottom holder.STL
90.0 x 25.0 x 70.0

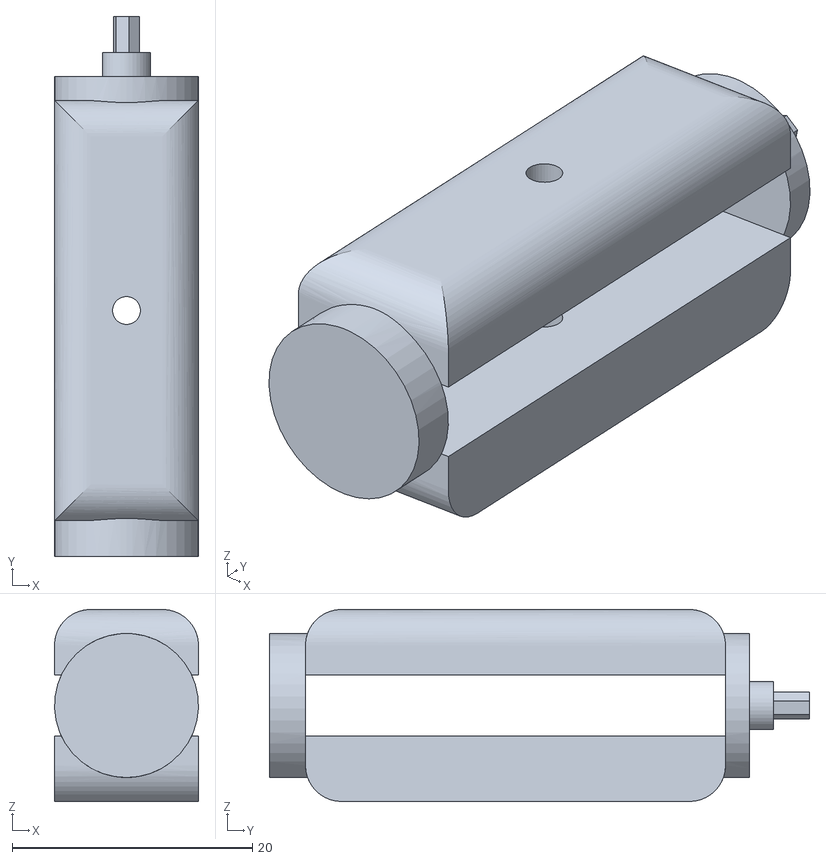
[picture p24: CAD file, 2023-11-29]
Cyber Glove/cyber glove/rachet_joint.STL
12.0 x 45.0 x 16.0

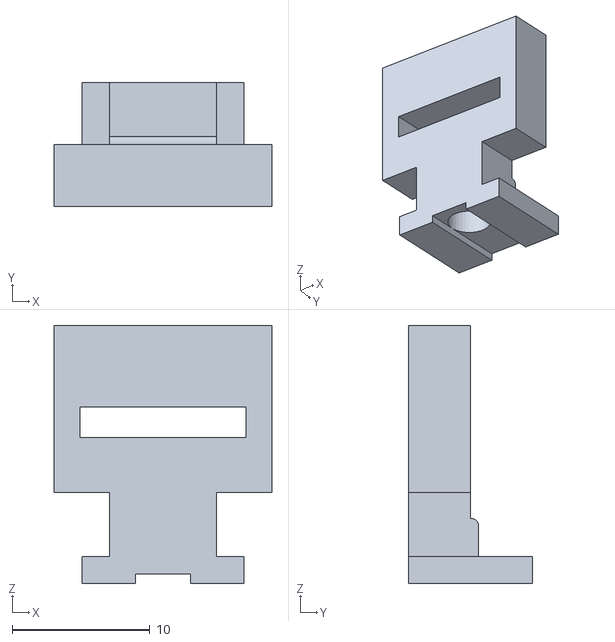
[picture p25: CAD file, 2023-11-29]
STL_Files_Left_Hand/slide1_1_1.STL
15.8 x 9.00 x 18.7

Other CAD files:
STL_Files_Left_Hand/Ratchet Joint sep.dwg
Cyber Glove/cyber glove/finger tip version1.STL
Cyber Glove/cyber glove/little finger cover.STL
Cyber Glove/cyber glove/little finger link.STL
Cyber Glove/cyber glove/mid_ring_ind_finger link.STL
Cyber Glove/cyber glove/pcbholder.STL
Cyber Glove/cyber glove/rachet link.STL
Cyber Glove/cyber glove/thbl2cvr.STL
Cyber Glove/cyber glove/thumb attachment.STL
Cyber Glove/cyber glove/thumb lower holder.STL
Cyber Glove/cyber glove/thumb upper holder.STL
Cyber Glove/cyber glove/tip with mot.STL
STL_Files_Left_Hand/Bottom Holder.dwg
STL_Files_Left_Hand/Pins1,2,3.dwg
STL_Files_Left_Hand/Pins1.stl
STL_Files_Left_Hand/Pins2.stl
STL_Files_Left_Hand/Pins3.stl
STL_Files_Left_Hand/Ratchet Joint 2.stl
STL_Files_Left_Hand/Ratchet Joint 4.stl
STL_Files_Left_Hand/Ratchet Joint.SLDPRT
STL_Files_Left_Hand/Ratchet Link.dwg
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

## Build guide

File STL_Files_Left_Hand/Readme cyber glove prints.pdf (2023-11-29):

Sr.no. | Name of file no. of prints for assembly
1 | rachet_joint.STL | 5
2 | slide_1_1_2.STL | 2
3 | slide1_1_1.STL | 2
4 | slider2.STL | 2
5 | thbl2cvr.STL | 1
6 | thumb attachment.STL | 1
7 | thumb cover.STL | 1
8 | thumb lower holder.STL | 1
9 | thumb upper holder.STL | 1
10 | thumblink.STL | 1
11 | tip with mot.STL | 2
12 | top holder.STL | 1
13 | bottom holder.STL | 1
14 | cover plate.STL | 1
15 | finger tip version1.STL | 3
16 | little finger cover.STL | 1
17 | little finger link.STL | 1
18 | mid_ring_ind_finger cover.STL | 3
19 | mid_ring_ind_finger link.STL | 3
20 | pcbholder.STL | 1
21 | rachet link cover.STL | 5
22 | rachet link.STL | 5

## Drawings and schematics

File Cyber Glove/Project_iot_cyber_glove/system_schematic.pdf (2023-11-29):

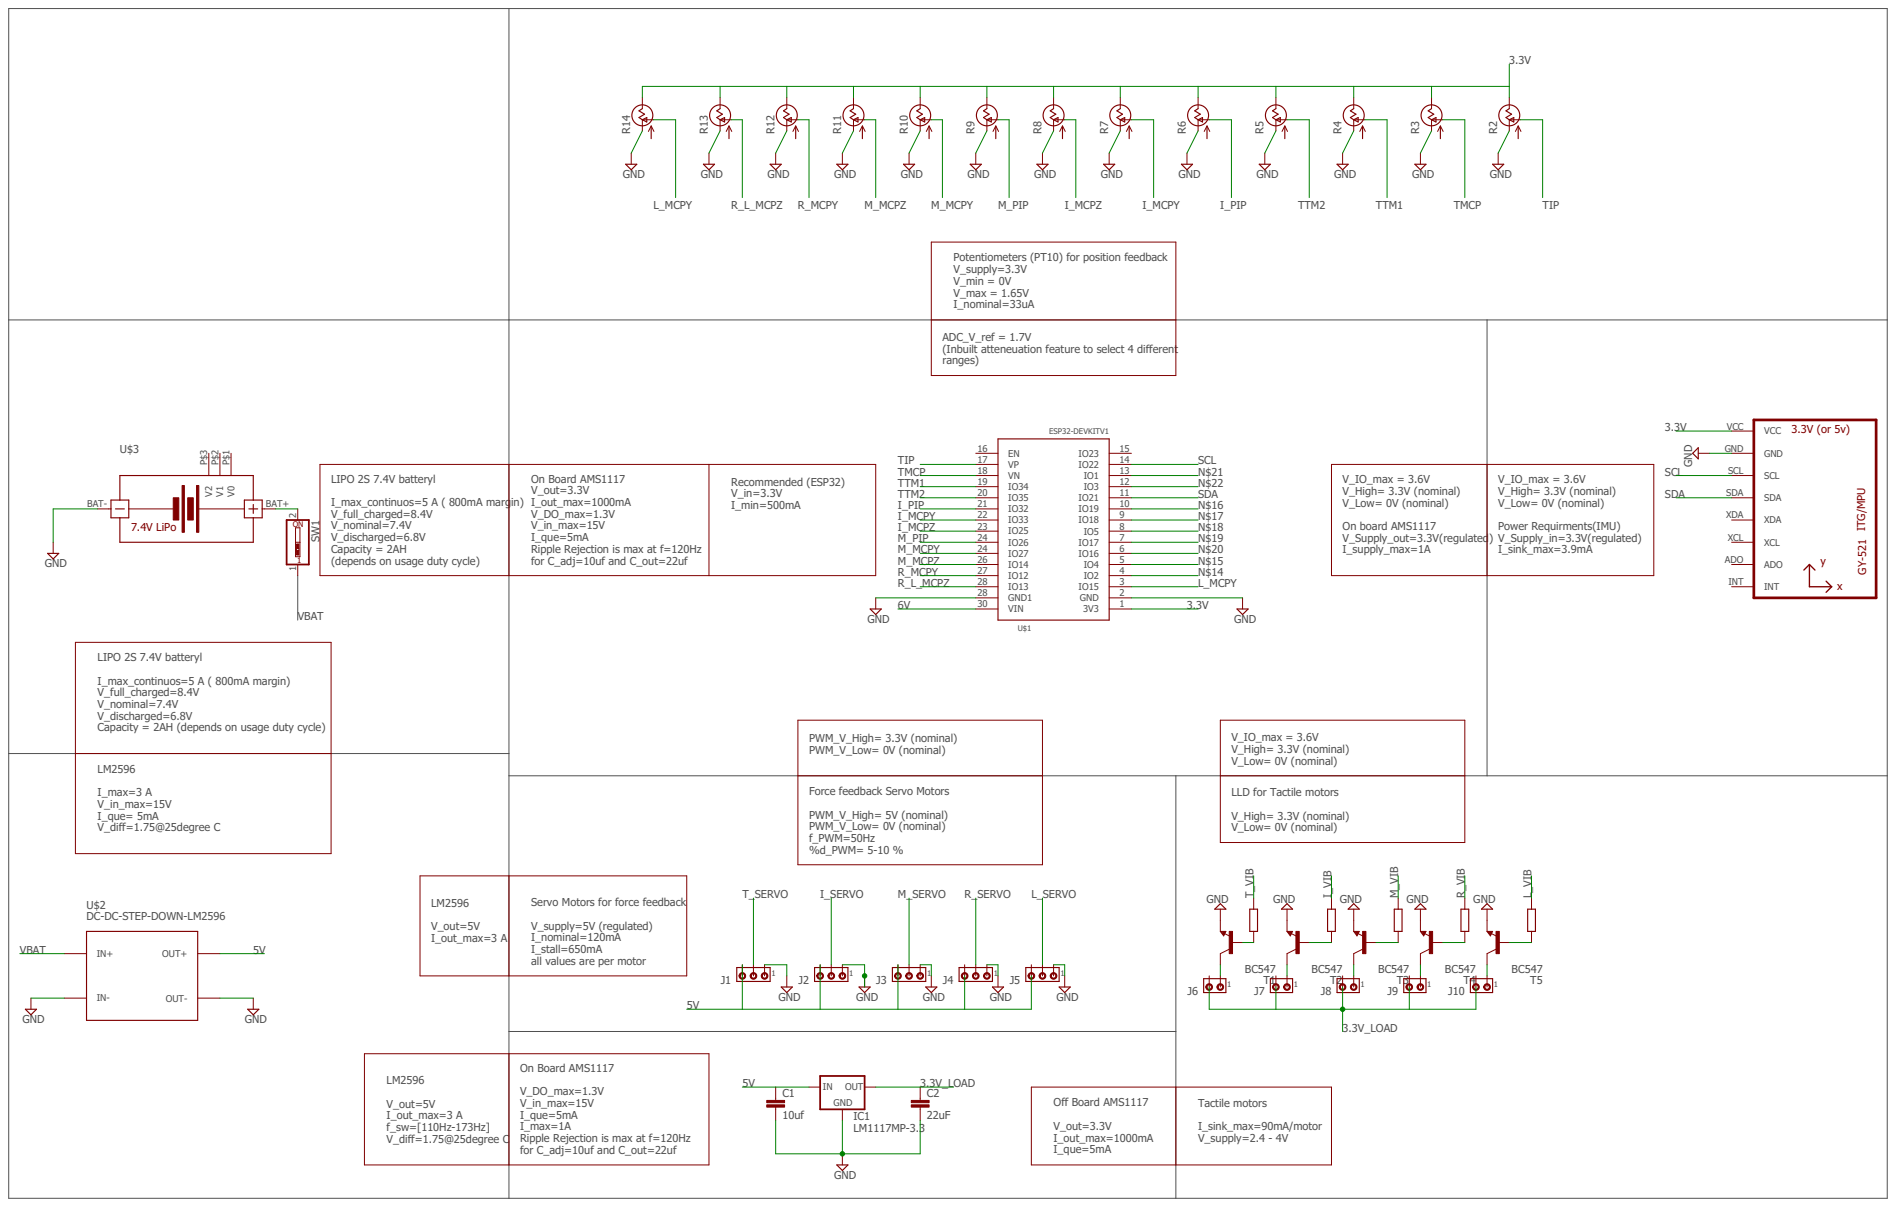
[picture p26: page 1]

ADC_V_ref = 1.7V
(Inbuilt atteneuation feature to select 4 different
ranges)

Force feedback Servo Motors

LLD for Tactile motors

Servo Motors for force feedback

DC-DC-STEP-DOWN-LM2596

LM2596 V_out=5V I_out_max=3 A f_sw=[110Hz-173Hz] V_diff=1.75@25degree C | On Board AMS1117 V_DO_max=1.3V V_in_max=15V I_que=5mA I_max=1A Ripple Rejection is max at f=120Hz for C_adj=10uf and C_out=22uf

Off Board AMS1117 V_out=3.3V I_out_max=1000mA I_que=5mA | Tactile motors I_sink_max=90mA/motor V_supply=2.4 - 4V

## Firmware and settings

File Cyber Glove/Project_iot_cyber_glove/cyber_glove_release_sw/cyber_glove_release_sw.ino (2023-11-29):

#include <WiFi.h> 
#include <WebServer.h> 
#include <ESP32Servo.h>
#include <ArduinoJson.h> 
#include <WebSocketsServer.h>
#include "I2Cdev.h"
#include "MPU6050_6Axis_MotionApps20.h"
#if I2CDEV_IMPLEMENTATION == I2CDEV_ARDUINO_WIRE
    #include "Wire.h"
#endif

/**************************imu******************************/
#define INTERRUPT_PIN 5
bool dmpReady = false;  // set true if DMP init was successful
uint8_t mpuIntStatus;   // holds actual interrupt status byte from MPU
uint8_t devStatus;      // return status after each device operation (0 = success, !0 = error)
uint16_t packetSize;    // expected DMP packet size (default is 42 bytes)
uint16_t fifoCount;     // count of all bytes currently in FIFO
uint8_t fifoBuffer[64]; // FIFO storage buffer

Quaternion q;           // [w, x, y, z]         quaternion container
VectorInt16 aa;         // [x, y, z]            accel sensor measurements
VectorInt16 aaReal;     // [x, y, z]            gravity-free accel sensor measurements
VectorInt16 aaWorld;    // [x, y, z]            world-frame accel sensor measurements
VectorFloat gravity;    // [x, y, z]            gravity vector
float euler[3];         // [psi, theta, phi]    Euler angle container
float ypr[3];           // [yaw, pitch, roll]   yaw/pitch/roll container and gravity vector

uint8_t teapotPacket[14] = { '$', 0x02, 0,0, 0,0, 0,0, 0,0, 0x00, 0x00, '\r', '\n' };

MPU6050 mpu;
/************************************************************/

/**************************angle sensor********************/
const uint8_t ind_fing_pin = 39;
const uint8_t mid_fing_pin = 34;
const uint8_t rng_fing_pin = 35;
const uint8_t lil_fing_pin = 32;
const uint8_t thumb_pin = 36;

float y_ind[3];
float y_mid[3];
float y_rng[3];
float y_lil[3];
float y_thb[3];

int x_ind[3];
int x_mid[3];
int x_rng[3];
int x_lil[3];
int x_thb[3];

float ang_ind;
float ang_mid;
float ang_rng;
float ang_lil;
float ang_thb;

/****************************2nd order BW fliter*****************/

const float a1 = 1.0;
const float a2 = 2.0;
const float a3 = 1.0;
const float b1 = 4.841;
const float b2 = 1.789;
const float b3 = -0.948;

/*******************************************************************/

/*************************calibration joint angle**************/
const float ind_off=878.0;
const float mid_off=785.0;
const float rng_off=1179.0;
const float lil_off=950.0;
const float thb_off=895.0;

const float ind_range=1794.0;
const float mid_range=1708.0;
const float rng_range=1684.0;
const float lil_range=1845.0;
const float thb_range=1958.0;

const float delta_ang=107.0;

/***************************************************************/

/**********************servo and vibration motors ***********/
const uint8_t vmot_thb_pin = 2;// options 19
const uint8_t vmot_ind_pin = 4;
const uint8_t ind_servo_pin = 33;
const uint8_t thb_servo_pin = 25;
const uint8_t led_pin=17;
/*****************************************************************/

/***************** calibation haptic and tactile ****************/
const uint8_t dutyCycle_max = 128;
const uint8_t dutyCycle_min = 0;
const uint8_t thb_servo_push = 140;
const uint8_t ind_servo_push = 80;
const uint8_t thb_servo_pull = 180;
const uint8_t ind_servo_pull = 180;
/*****************************************************************/

uint8_t ff_status = 0;
uint8_t tf_status = 0;

Servo thbservo;
Servo indservo;
Servo led;
/************************your wifi router credentials***********************************/

const char* ssid = "NATURE";  
const char* password = "sut3omki"; 
/***********************************************************************/

/***********************joint angle sampling***************************/
int interval = 20; // sample time
unsigned long previousMillis = 0; // time stamp for last sample
/***************************************************/

/*********************** webpage*********************************/
String web ="<!DOCTYPE html><html><head> <title>Arduino and ESP32 Websocket</title> <meta name='viewport' content='width=device-width, initial-scale=1.0' /> <meta charset='UTF-8'> <style> body { background-color: #E6D8D5; text-align: center; } </style></head><body> <h1>INDEX FINGER ANGLE: <span id='indang'>-</span></h1> <h1>MIDDLE FINGER ANGLE: <span id='midang'>-</span></h1> <h1>RING FINGER ANGLE: <span id='rngang'>-</span></h1> <h1>LITLE FINGER ANGLE: <span id='lilang'>-</span></h1> <h1>THUMB ANGLE: <span id='thbang'>-</span></h1> <h1>ROLL: <span id='roll'>-</span></h1> <h1>PITCH: <span id='pitch'>-</span></h1> <h1>YAW: <span id='yaw'>-</span></h1> <h1>FORCE FEEDBACK: <span id='ff'>-</span></h1> <button type='button' id='BTN_1'> <h1>ON</h1> </button><button type='button' id='BTN_2'> <h1>OFF</h1> </button> <h1>TACTILE FEEDBACK: <span id='tf'>-</span></h1> <button type='button' id='BTN_3'> <h1>ON</h1> </button><button type='button' id='BTN_4'> <h1>OFF</h1> </button></body><script> var Socket; document.getElementById('BTN_1').addEventListener('click', button_1_pressed); document.getElementById('BTN_2').addEventListener('click', button_2_pressed); document.getElementById('BTN_3').addEventListener('click', button_3_pressed); document.getElementById('BTN_4').addEventListener('click', button_4_pressed); function init() { Socket = new WebSocket('ws://' + window.location.hostname + ':81/'); Socket.onmessage = function(event) { processCommand(event); }; } function processCommand(event) { var obj = JSON.parse(event.data); document.getElementById('indang').innerHTML = obj.indang; document.getElementById('midang').innerHTML = obj.midang; document.getElementById('rngang').innerHTML = obj.rngang; document.getElementById('lilang').innerHTML = obj.lilang; document.getElementById('thbang').innerHTML = obj.thbang; document.getElementById('roll').innerHTML = obj.roll; document.getElementById('pitch').innerHTML = obj.pitch; document.getElementById('yaw').innerHTML = obj.yaw; document.getElementById('ff').innerHTML = obj.ff; document.getElementById('tf').innerHTML = obj.tf; console.log(obj.indang); console.log(obj.midang); console.log(obj.rngang); console.log(obj.lilang); console.log(obj.thbang); console.log(obj.roll); console.log(obj.pitch); console.log(obj.yaw); console.log(obj.ff); console.log(obj.tf); } function button_1_pressed() { Socket.send('0'); } function button_2_pressed() { Socket.send('1'); } function button_3_pressed() { Socket.send('2'); } function button_4_pressed() { Socket.send('3'); } window.onload = function(event) { init(); }</script></html>";
String jsonString; // Temporary storage for the JSON String
/************************************************************/

WebServer server(80);  // create instance for web server on port "80"
WebSocketsServer webSocket = WebSocketsServer(81);  //create instance for webSocket server on port"81"


/****************************************imu**********************************/
/*============================================================================*/
volatile bool mpuInterrupt = false;     // indicates whether MPU interrupt pin has gone high
void dmpDataReady() {
    mpuInterrupt = true;
}

void setup_imu()
{
// join I2C bus (I2Cdev library doesn't do this automatically)
    
    #if I2CDEV_IMPLEMENTATION == I2CDEV_ARDUINO_WIRE
        Wire.begin();
        Wire.setClock(400000); // 400kHz I2C clock. Comment this line if having compilation difficulties
    #elif I2CDEV_IMPLEMENTATION == I2CDEV_BUILTIN_FASTWIRE
        Fastwire::setup(400, true);
    #endif
    
    /************************ initialize device************************/
    Serial.println(F("Initializing I2C devices..."));
    mpu.initialize();
    pinMode(INTERRUPT_PIN, INPUT);
    
    /************************ verify connection************************/
    Serial.println(F("Testing device connections..."));
    Serial.println(mpu.testConnection() ? F("MPU6050 connection successful") : F("MPU6050 connection failed"));

    Serial.println(F("Initializing DMP..."));
    devStatus = mpu.dmpInitialize();

    /*****************************imu calibration********************/
    mpu.setXGyroOffset(220);
    mpu.setYGyroOffset(76);
    mpu.setZGyroOffset(-85);
    mpu.setZAccelOffset(1788); 


    if (devStatus == 0) {
        // Calibration Time: generate offsets and calibrate our MPU6050
        mpu.CalibrateAccel(6);
        mpu.CalibrateGyro(6);
        mpu.PrintActiveOffsets();
        // turn on the DMP, now that it's ready
        Serial.println(F("Enabling DMP..."));
        mpu.setDMPEnabled(true);

        // enable Arduino interrupt detection
        Serial.print(F("Enabling interrupt detection (Arduino external interrupt "));
        Serial.print(digitalPinToInterrupt(INTERRUPT_PIN));
        Serial.println(F(")..."));
        attachInterrupt(digitalPinToInterrupt(INTERRUPT_PIN), dmpDataReady, RISING);
        mpuIntStatus = mpu.getIntStatus();

        // set our DMP Ready flag so the main loop() function knows it's okay to use it
        Serial.println(F("DMP ready! Waiting for first interrupt..."));
        dmpReady = true;
        Serial.print("dmpready : ");
        Serial.print(dmpReady);
        Serial.println(" ");

        // get expected DMP packet size for later comparison
        packetSize = mpu.dmpGetFIFOPacketSize();
    } else {
        // ERROR!
        // 1 = initial memory load failed
        // 2 = DMP configuration updates failed
        // (if it's going to break, usually the code will be 1)
        Serial.print(F("DMP Initialization failed (code "));
        Serial.print(devStatus);
        Serial.println(F(")"));
    }

}

void update_imu()
{
  if (!dmpReady) return;
  if (mpu.dmpGetCurrentFIFOPacket(fifoBuffer))
  {
    mpu.dmpGetQuaternion(&q, fifoBuffer);
    mpu.dmpGetGravity(&gravity, &q);
    mpu.dmpGetYawPitchRoll(ypr, &q, &gravity);
  }
}
/*============================================================================*/
/****************************************end imu********************************/

/************************************ADC for joint angles****************/
/*----------------------------------------------------------------------*/
void push_y(float *stack,float value)
{
  int i=2;
  for (i=2;i>0;i--)
    stack[i]=stack[i-1];
  stack[0]=value;
}
void filtered_values(float *y,int *x)
{
  float y_out;
  y_out = (a1*x[0]+a2*x[1]+a3*x[2]+b2*y[1]+b3*y[2])/b1;
  push_y(y,y_out);
}

void push_x(int *stack,int value)
{
  int i=2;
  for (i=2;i>0;i--)
    stack[i]=stack[i-1];
  stack[0]=value;
}




void update_fing_values()
{
  int raw_ind;
  int raw_mid;
  int raw_rng;
  int raw_lil;
  int raw_thb;
  
  raw_ind = analogRead(ind_fing_pin);
  raw_mid = analogRead(mid_fing_pin);
  raw_rng = analogRead(rng_fing_pin);
  raw_lil = analogRead(lil_fing_pin);
  raw_thb = analogRead(thumb_pin);
  
  push_x(x_ind,raw_ind);
  push_x(x_mid,raw_mid);
  push_x(x_rng,raw_rng);
  push_x(x_lil,raw_lil);
  push_x(x_thb,raw_thb);
  
  filtered_values(y_ind,x_ind);
  filtered_values(y_mid,x_mid);
  filtered_values(y_rng,x_rng);
  filtered_values(y_lil,x_lil);
  filtered_values(y_thb,x_thb);

  ang_ind = (y_ind[0]-ind_off)*(delta_ang/ind_range);
  ang_mid = (y_mid[0]-mid_off)*(delta_ang/mid_range);
  ang_rng = (y_rng[0]-rng_off)*(delta_ang/rng_range);
  ang_lil = (y_lil[0]-lil_off)*(delta_ang/lil_range);
  ang_thb = (y_thb[0]-thb_off)*(delta_ang/thb_range);
}
/*---------------------------------------------------------------------*/
/*************************************END**********************************/

///**************************tactile and force feedback*******************/
///*-----------------------------------------------------------------------*/
void setup_feedback()
{
  ESP32PWM::allocateTimer(0);
  ESP32PWM::allocateTimer(1);
  ESP32PWM::allocateTimer(2);
  ESP32PWM::allocateTimer(3);
  thbservo.setPeriodHertz(50); 
  indservo.setPeriodHertz(50); 
  pinMode(vmot_thb_pin,OUTPUT);
  pinMode(vmot_ind_pin,OUTPUT);
}
  void activate_foce_feedback()
  {
    thbservo.attach(thb_servo_pin, 1000, 2000);
    indservo.attach(ind_servo_pin, 1000, 2000);
    thbservo.write(thb_servo_push);
    indservo.write(ind_servo_push);
    ff_status=1;
  }
  
  void deactivate_foce_feedback()
  {
    thbservo.attach(thb_servo_pin, 1000, 2000);
    indservo.attach(ind_servo_pin, 1000, 2000);
    thbservo.write(thb_servo_pull);
    indservo.write(ind_servo_pull);
    ff_status=0;
  } 
  
void activate_tactile_feedback()
{ 
    pinMode(vmot_thb_pin,OUTPUT); 
    digitalWrite(vmot_thb_pin,HIGH);
    pinMode(vmot_ind_pin,OUTPUT);
    digitalWrite(vmot_ind_pin,HIGH);      
  tf_status=1;
}

void deactivate_tactile_feedback()
{
  digitalWrite(2,LOW);  
  digitalWrite(4,LOW);
  tf_status=0;
}   
/*-----------------------------------------------------------------------*/
/********************************************END*******************************/
 
/*********************************websocket*********************************/
void webSocketEvent(byte num, WStype_t type, uint8_t * payload, size_t length) {
  switch (type) {
    case WStype_DISCONNECTED: // enum that read status this is used for debugging.
      Serial.print("WS Type ");
      Serial.print(type);
      Serial.println(": DISCONNECTED");
      break;
    case WStype_CONNECTED:  // Check if a WebSocket client is connected or not
      Serial.print("WS Type ");
      Serial.print(type);
      Serial.println(": CONNECTED");
      /********************************/
      /*****add code for led **********/
      break;
    case WStype_TEXT: // check responce from client
      Serial.println(); // the payload variable stores teh status internally
      Serial.println(payload[0]);
      if (payload[0] == '3') { 
        activate_foce_feedback(); 
        activate_tactile_feedback();             
      }
      if (payload[0] == '1') {
        deactivate_foce_feedback(); 
        activate_tactile_feedback();
      }
      if (payload[0] == '0') {        
        deactivate_foce_feedback();
        deactivate_tactile_feedback();             
      }
      break;
  }
}

void update_webpage()
{
  StaticJsonDocument<200> doc;
  // create an object
  JsonObject object = doc.to<JsonObject>();
  object["indang"]=(uint8_t)ang_ind;
  object["midang"]=(uint8_t)ang_mid;
  object["rngang"]=(uint8_t)ang_rng;
  object["lilang"]=(uint8_t)ang_lil;
  object["thbang"]=(uint8_t)ang_thb;
  object["roll"]=ypr[2]* 180/M_PI;
  object["pitch"]=ypr[1] * 180/M_PI;
  object["yaw"]=ypr[0] * 180/M_PI;
  object["ff"] = ff_status ;
  object["tf"]= tf_status;
  serializeJson(doc, jsonString); // serialize the object and save teh result to teh string variable.
  Serial.println( jsonString ); // print the string for debugging.
  webSocket.broadcastTXT(jsonString); // send the JSON object through the websocket
  jsonString = ""; // clear the String.
}

void setup() {
  // put your setup code here, to run once:
  led.setPeriodHertz(10);
  led.attach(led_pin,0,50000);
  led.write(180);
  Serial.begin(115200); // Init Serial for Debugging.
  WiFi.begin(ssid, password); // Connect to Wifi 
  while (WiFi.status() != WL_CONNECTED) { // Check if wifi is connected or not
    delay(500);
    Serial.print(".");
  }
  Serial.println();
  // Print the IP address in the serial monitor windows.
  Serial.print("IP address: ");
  Serial.println(WiFi.localIP());
  // Initialize a web server on the default IP address. and send the webpage as a response.
  server.on("/", []() {
    server.send(400, "text\html", web);
  });
  server.begin(); // init the server
  webSocket.begin();  // init the Websocketserver
  webSocket.onEvent(webSocketEvent);  // init the webSocketEvent function when a websocket event occurs 
  //setup_feedback();
  setup_imu();
  led.detach();
  pinMode(led_pin,OUTPUT);
  digitalWrite(led_pin,HIGH);
}

void loop() 
{
  server.handleClient();  // webserver methode that handles all Client
  webSocket.loop(); // websocket server methode that handles all Client
  unsigned long currentMillis = millis(); // call millis  and Get snapshot of time
  if ((unsigned long)(currentMillis - previousMillis) >= interval) 
  { // How much time has passed, accounting for rollover with subtraction!
    update_fing_values();
    update_imu();
    update_webpage(); 
    previousMillis = currentMillis;   // Use the snapshot to set track time until next event
  }
}

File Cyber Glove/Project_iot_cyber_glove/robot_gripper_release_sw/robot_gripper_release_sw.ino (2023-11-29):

#include <WiFi.h> // ESP32 WiFi Library
#include <WebServer.h> // WebServer Library for ESP32
#include <ESP32Servo.h>
#include <WebSocketsClient.h> // WebSocket Client Library for WebSocket
#include <ArduinoJson.h> // Arduino JSON Library

const uint8_t ind_sense_pin = 34;
const uint8_t thumb_sense_pin = 35;

const uint8_t ind_servo_pin = 26;
const uint8_t thb_servo_pin = 25;
const uint8_t knkl_pitch_servo_pin=32;
const uint8_t knkl_roll_servo_pin=33;

const uint8_t ind_open_ang=0;
const uint8_t ind_close_ang=70;
const uint8_t thb_open_ang=85;
const uint8_t thb_close_ang=0;
const uint8_t knkl_roll_min = 0;
const uint8_t knkl_roll_max = 180;
const uint8_t knkl_pitch_min = 0;
const uint8_t knkl_pitch_mid = 90;
const uint8_t knkl_pitch_max = 180;

float y_ind_sense[3];
float y_thb_sense[3];

int x_ind_sense[3];
int x_thb_sense[3];

const uint16_t tf_thld=1000;
const uint16_t ff_thld=2500;

const uint8_t glove_open_cal=20;
const uint8_t glove_pinch_cal=120;
const int16_t glove_roll_cal_low=0;
const int16_t glove_roll_cal_high=-180;
const int16_t glove_pitch_cal_low=-90;
const int16_t glove_pitch_cal_high=90;

const float a1 = 1.0;
const float a2 = 2.0;
const float a3 = 1.0;
const float b1 = 4.841;
const float b2 = 1.789;
const float b3 = -0.948;

uint8_t _indang;
uint8_t _midang;
uint8_t _rngang;
uint8_t _lilang;
uint8_t _thbang;
uint16_t _roll;
uint16_t _pitch;
uint16_t _yaw;
uint8_t ff_status;
uint8_t tf_status;

int interval = 20; // virtual delay
unsigned long previousMillis = 0; // Tracks the time since last event fired


// Wifi Credentials
const char* ssid = "NATURE"; // Wifi SSID
const char* password = "sut3omki"; //Wi-FI Password
WebSocketsClient webSocket; // websocket client class instance
StaticJsonDocument<200> doc; // Allocate a static JSON document

Servo thbservo;
Servo indservo;
Servo knklrollservo;
Servo knklpitchservo;

/*************************Pressure Sensors**************************/

void push_y(float *stack,float value)
{
  int i=2;
  for (i=2;i>0;i--)
    stack[i]=stack[i-1];
  stack[0]=value;
}
void filtered_values(float *y,int *x)
{
  float y_out;
  y_out = (a1*x[0]+a2*x[1]+a3*x[2]+b2*y[1]+b3*y[2])/b1;
  push_y(y,y_out);
}

void push_x(int *stack,int value)
{
  int i=2;
  for (i=2;i>0;i--)
    stack[i]=stack[i-1];
  stack[0]=value;
}

void update_fing_values()
{
  int raw_ind;
  int raw_thb;
  
  raw_ind = analogRead(ind_sense_pin);
  raw_thb = analogRead(thumb_sense_pin);
  
  push_x(x_ind_sense,raw_ind);
  push_x(x_thb_sense,raw_thb);
  
  filtered_values(y_ind_sense,x_ind_sense);
  filtered_values(y_thb_sense,x_thb_sense);
}
/*******************************************************************/

/************************servo drive*********************************/
void setup_servo()
{
  ESP32PWM::allocateTimer(0);
  ESP32PWM::allocateTimer(1);
  ESP32PWM::allocateTimer(2);
  ESP32PWM::allocateTimer(3);
  thbservo.setPeriodHertz(50); 
  indservo.setPeriodHertz(50); 
  knklrollservo.setPeriodHertz(50);
  knklpitchservo.setPeriodHertz(50);
}

void servo_attach()
{ 
  thbservo.attach(thb_servo_pin, 400, 2200);
  indservo.attach(ind_servo_pin, 500, 2200); 
  knklrollservo.attach(knkl_roll_servo_pin, 900, 2400);
  knklpitchservo.attach(knkl_pitch_servo_pin, 700, 2400);  
}
/********************************************************************/

void webSocketEvent(WStype_t type, uint8_t * payload, size_t length) {
  if (type == WStype_TEXT)
  {
    // deserialize incoming Json String
    DeserializationError error = deserializeJson(doc, payload); 
    if (error) 
    { // Print erro msg if incomig String is not JSON formated
      Serial.print(F("deserializeJson() failed: "));
      Serial.println(error.c_str());
      return;
    }
    _indang =(uint8_t) doc["indang"];
    _midang=_indang;
//    _midang =(uint8_t) doc["midang"];
//    _rngang =(uint8_t) doc["rngang"];
//    _lilang =(uint8_t) doc["lilang"];
    _thbang =(uint8_t) doc["thbang"];
    _indang=map((_indang+_thbang),15,90,0,80);
    _thbang=map((_midang+_thbang),15,90,85,0);
    //_midang=map(_thbang+_indang,glove_open_cal,glove_pinch_cal,90,0);
    //_indang=map(_midang,0,90,ind_close_ang,ind_open_ang);
    //_thbang=map(midang,0,90,thb_close_ang,thb_open_ang);
    _roll =(int16_t) doc["roll"]+180;//,glove_roll_cal_low,glove_roll_cal_high,knkl_roll_min,knkl_roll_max);
    _pitch =(int16_t) doc["pitch"]+90;//,glove_pitch_cal_low,glove_pitch_cal_high,knkl_pitch_min,knkl_pitch_max);
    if(_indang<81 && _indang>=0)
    thbservo.write(_thbang);
    if(_thbang<86 && _thbang>=0)
    indservo.write(_indang); 
    if(_roll<181 && _roll>=0)
    knklrollservo.write(_roll);
    if(_pitch<181 && _pitch>=0)
    knklpitchservo.write(_pitch);   
   // _yaw =(int16_t) doc["yaw"];
    ff_status =(uint8_t) doc["ff"];
    tf_status = (uint8_t) doc["tf"];
  }
}

void setup() {
  // Connect to local WiFi
  WiFi.begin(ssid, password);
  setup_servo();
  servo_attach();
  Serial.begin(115200);
  while (WiFi.status() != WL_CONNECTED) {
    Serial.print(".");
    delay(500);
  }
  Serial.println();
  Serial.print("IP Address: ");
  Serial.println(WiFi.localIP()); // Print local IP address
  //address, port, and URL path
  webSocket.begin("192.168.0.153", 81, "/");// server IP
  // WebSocket event handler
  webSocket.onEvent(webSocketEvent);
  // if connection failed retry every 5s
  webSocket.setReconnectInterval(5000);
}

void loop() 
{
  webSocket.loop(); // Keep the socket alive 
  unsigned long currentMillis = millis(); // call millis  and Get snapshot of time
  if ((unsigned long)(currentMillis - previousMillis) >= interval) 
  { // How much time has passed, accounting for rollover with subtraction!
    update_fing_values();
//    if(y_ind_sense[0]>tf_thld && y_ind_sense[0]<ff_thld)
//      webSocket.sendTXT('1');
    if(y_thb_sense[0]<ff_thld && tf_status==1)
     { webSocket.sendTXT('0');
     Serial.println("off");
     }
    if(y_thb_sense[0]>ff_thld && tf_status==0)
    {
      webSocket.sendTXT('3'); 
      Serial.println(tf_status);
    }                
    previousMillis = currentMillis;   // Use the snapshot to set track time until next event
  }
}

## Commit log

2023-11-29 project add
    [Bottom Holder.dwg, Pins1,2,3.dwg, Pins1.stl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]
2025-10-30 Improve README with comprehensive documentation and image sections
    - Added detailed project overview and description
    - Created table of contents for easy navigation
    - Added comprehensive sections: Features, System Architecture, Hardware/Software Components
    - Included detailed pin configuration for ESP32
    - Added installation and usage instructions
    - Documented MQTT communication protocol and data format
    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
